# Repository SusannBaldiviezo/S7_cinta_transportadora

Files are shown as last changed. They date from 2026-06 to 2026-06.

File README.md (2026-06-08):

Markdown# Sistema Automático de Clasificación de Frutas

**Universidad:** Universidad Católica Boliviana "San Pablo"
**Materia:** Sistemas Embebidos II
**Docente:** Msc. Ing. Alan Cornejo Q.

**Universidad:** Universidad Católica Boliviana "San Pablo"  
**Materia:** Sistemas Embebidos II  
**Docente:** Msc. Ing. Alan Cornejo Q.  

**Semestre:** 1/2026
=======
**Semestre:** 1/2026  

**Estudiantes:** - Susann Baldiviezo C.  
- Alejandro Bejarano R.  
- Florencia Frigerio A.  
- Benjamín Soruco G.  

---

## Descripción

El objetivo principal de este proyecto es automatizar, mediante una cinta transportadora, la selección y clasificación de tomates en las zonas productoras del departamento de Tarija. Para dar solución a esta necesidad, se presenta este prototipo a escala como una alternativa tecnológica eficiente.

El sistema realiza la clasificación automática mediante visión artificial y un microcontrolador ESP32. Detecta tomates en estado de descomposición a través de dos cámaras USB y OpenCV, activa un mecanismo de desviación controlado por **dos servomotores** para expulsarlos de la banda transportadora, y permite al operario monitorear y controlar todo el proceso desde una consola portátil inalámbrica.

## Arquitectura general

[2 Cámaras USB]│▼[PC — Python + OpenCV]  ──────────────────────────────────────────┐│  publica fruta/estado                                     │▼                                                           │[Raspberry Pi — Mosquitto MQTT]  (AP: CintaTransportadora)        ││  distribuye                                               │├────────────────────────┐                                  │▼                        ▼                                  │[ESP32 Motor]          [ESP32 Consola]  ◄── operario              │BTS7960                Pantalla OLED                           │Banda DC               4 botones                               │2 Servomotores                                                 ││                        │                                  │▼                        ▼                                  │[Motor 12V]          [Pantalla de estado]  ───────────────────────┘[Mecanismo Desviador]
## Estructura del repositorio

├── README.md              ← este archivo├── ARCHITECTURE.md        ← diagrama detallado del sistema├── SETUP.md               ← cómo levantar el proyecto de cero├── .gitignore│├── docs/                  ← documentación completa├── esp32/                 ← firmware embebido (motor + consola)├── hardware/              ← conexiones, pinouts, datasheets├── ml/                    ← módulo de visión artificial (OpenCV/YOLO)├── rpi/                   ← scripts Python para la Raspberry Pi├── scripts/               ← herramientas y simuladores├── config/                ← configuración de servicios (Mosquitto, etc.)├── requirements/          ← dependencias por módulo├── tests/                 ← pruebas de integración└── dashboard/             ← interfaz web 
## Inicio rápido

```bash
# 1. Clonar el repositorio
git clone <url-del-repo>
cd S7_cinta_transportadora

# 2. Ver guía de instalación
cat SETUP.md

# 3. Instalar dependencias Python
pip install -r requirements/rpi_requirements.txt

# 4. Compilar y flashear ESP32 motor (desde esp32/motor_controller/)
idf.py build
idf.py -p COM3 flash monitor

# 5. Compilar y flashear ESP32 consola (desde esp32/console_esp32/)
idf.py build
idf.py -p COM4 flash monitor

# 6. Ejecutar el sistema principal
python ml/main_vision.py
Estado del proyectoComponenteEstadoRPi + Mosquitto MQTT✅ CompletadoESP32 Motor (BTS7960 + 2 Servomotores)✅ CompletadoRPi como Access Point✅ CompletadoESP32 Consola (Pantalla OLED + botones)✅ CompletadoMódulo OpenCV (Visión artificial para tomates)✅ CompletadoIntegración y Pruebas en Banda✅ CompletadoDashboard web✅ Completado

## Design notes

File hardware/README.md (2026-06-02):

# Hardware

## Lista de componentes

| ID | Componente | Descripción | Estado |
|---|---|---|---|
| H-01 | ESP32 WROOM-32 | Microcontrolador principal (motor) | ✅ |
| H-02 | 2x Cámaras USB | Captura de imágenes de frutas | ⬜ pendiente |
| H-03 | Cilindro neumático | Expulsión física de fruta rechazada | ✅ |
| H-04 | Válvula solenoide 12V | Controla aire al cilindro (via relé) | ✅ |
| H-05 | Motor DC 12V + banda | Transporte de fruta | ✅ |
| H-06 | Compresor de aire | Suministro neumático | ✅ |
| H-07 | PC/Laptop | Procesamiento OpenCV | ✅ |
| H-08 | Fuente 12V | Alimenta motor y válvula | ✅ |
| H-09 | Iluminación LED | Luz controlada sobre zona de inspección | ⬜ pendiente |
| H-10 | ESP32 WROOM-32 | Microcontrolador consola portátil | ✅ |
| H-11 | LCD 16x2 I2C | Display consola (módulo PCF8574) | ✅ |
| H-12 | Powerbank 5V | Alimentación autónoma consola | ✅ |
| H-13 | 4x pulsadores | Botones de control operario | ✅ |
| H-14 | LED + resistencia 220Ω | Indicador de alerta | ✅ |
| H-15 | BTS7960 (IBT-2) | Driver puente H para motor DC | ✅ |
| H-16 | Relé 5V | Control de válvula solenoide | ✅ |

## Conexiones ESP32 Motor ↔ BTS7960

```
ESP32 GPIO 25  →  BTS7960 RPWM   (PWM giro adelante)
ESP32 GPIO 26  →  BTS7960 LPWM   (PWM giro atrás)
ESP32 GPIO 32  →  BTS7960 R_EN   (habilita lado derecho)
ESP32 GPIO 33  →  BTS7960 L_EN   (habilita lado izquierdo)
ESP32 5V (VIN) →  BTS7960 VCC
ESP32 GND      →  BTS7960 GND    ← tierra común obligatoria

Fuente 12V (+) →  BTS7960 B+
Fuente 12V (-) →  BTS7960 B-     ← misma tierra común
BTS7960 M+     →  Motor (+)
BTS7960 M-     →  Motor (-)
```

## Conexiones ESP32 Motor ↔ Relé ↔ Válvula

```
ESP32 GPIO 27   →  Relé IN
ESP32 5V (VIN)  →  Relé VCC
ESP32 GND       →  Relé GND      ← tierra común
Fuente 12V (+)  →  Relé COM
Relé NO         →  Válvula (+)
Válvula (-)     →  Fuente 12V (-) ← tierra común
```

## Conexiones ESP32 Consola ↔ LCD I2C

```
ESP32 GPIO 21  →  LCD SDA
ESP32 GPIO 22  →  LCD SCL
ESP32 5V (VIN) →  LCD VCC
ESP32 GND      →  LCD GND

Dirección I2C por defecto: 0x27
(Si no funciona, probar: 0x3F)
```

## Conexiones Botones y LED (consola)

```
GPIO 14 → Botón INICIAR → GND   (pull-up interno activo)
GPIO 27 → Botón DETENER → GND
GPIO 26 → Botón PANTALLA → GND
GPIO 25 → Botón RESET → GND
GPIO 2  → Resistencia 220Ω → LED ánodo → LED cátodo → GND
```

## Tierra común — crítica

Todos los GND deben estar unidos:
- ESP32 GND
- BTS7960 GND (señales)
- BTS7960 B- (potencia)
- Fuente 12V (-)
- Relé GND

Sin tierra común, el sistema se comporta de forma errática.

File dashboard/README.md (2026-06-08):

# Sistema Clasificador de Frutas — Dashboard

Panel de control web en tiempo real para el sistema de clasificación de tomates con cinta transportadora.  
Desarrollado para UCB San Pablo · Sistemas Embebidos II · 2026.

---

## Arquitectura general

```
[ESP32 Cinta]  ──────────┐
                         ├─── WiFi ───► [Raspberry Pi AP]
[ESP32 Consola] ─────────┘               192.168.4.1
    (botones + OLED)                      │
                                          ├─ Mosquitto MQTT :1883
                                          ├─ FastAPI backend :8080
                                          └─ React frontend (servido por FastAPI)
```

La Raspberry Pi actúa como **punto de acceso WiFi** con SSID `CintaTransportadora`. Cualquier dispositivo conectado a esa red puede abrir el dashboard en `http://192.168.4.1:8080`.

---

## Estructura del proyecto

```
dashboard/
├── main.py            # Backend FastAPI + bridge MQTT (paho-mqtt)
├── data/
│   └── frutas.csv     # Historial persistente de clasificaciones
├── static/            # Build de React (generado con npm run build)
│   ├── index.html
│   └── assets/
└── frontend/          # Código fuente React + Vite
    ├── src/
    │   ├── App.jsx
    │   ├── index.css          # Sistema de diseño (variables CSS, tipografías)
    │   ├── api.js             # Llamadas HTTP al backend
    │   ├── hooks/
    │   │   └── useDashboard.js  # Polling cada 1500ms
    │   └── components/
    │       ├── Header.jsx
    │       ├── StatusCards.jsx
    │       ├── ControlPanel.jsx
    │       ├── AdminPanel.jsx
    │       ├── ConveyorPanel.jsx   # Animación cinta + bins de clasificación
    │       ├── CameraPanel.jsx     # Vista cámara + resultado de clasificación
    │       ├── OledMirror.jsx      # Espejo de la OLED del ESP32 Consola
    │       ├── CountersPanel.jsx
    │       ├── ChartsRow.jsx
    │       └── HistoryTable.jsx
    └── package.json
```

---

## MQTT — Tópicos

| Tópico | Dirección | Contenido |
|---|---|---|
| `fruta/estado` | ESP32 Cinta → todos | `aceptada` / `podrida` / `verde` |
| `sistema/motor` | ESP32 Cinta → todos | `activo` / `detenido` |
| `operario/comando`  | Dashboard/Consola → Cinta | `iniciar` / `detener` |
| `operario/pantalla` | Dashboard → Consola | Número de pantalla `0`, `1`, `2` |
| `operario/reset` | Dashboard → Consola | `reset` |
| `consola/pantalla`  | ESP32 Consola → Dashboard | Número de pantalla al presionar BTN |
| `consola/reset` | ESP32 Consola → Dashboard | `reset` al presionar BTN_RESET |

### Sincronización bidireccional

- **Botones ESP32 → Dashboard**: el ESP32 publica en `operario/comando`, `consola/pantalla` y `consola/reset`. El backend escucha y actualiza el estado. El frontend hace polling cada 1,5 s.
- **Dashboard → ESP32**: el backend publica en `operario/comando`, `operario/pantalla` y `operario/reset`. El ESP32 Consola está suscrito a todos estos.

---

## OLED Consola (SSD1306 128×64)

Tres pantallas, se ciclan con BTN_PANTALLA (GPIO 16) o desde el botón "Cambiar Pantalla" del dashboard:

| Pantalla | Contenido |
|---|---|
| 0 — CONTADORES FRUTA | Aceptadas / Podridas / Verdes + estado motor |
| 1 — DIAGNOSTICO SIST | Total clasificadas + rechazos consecutivos |
| 2 — SISTEMA ALERTAS  | Alerta parpadeante si rechazos consecutivos ≥ 3 |

El panel **Consola OLED** en el dashboard es un espejo fiel de lo que muestra el ESP32. Desde ahí también se puede:

- **Cambiar Pantalla** → publica `operario/pantalla` vía MQTT (el ESP32 cambia su OLED físico)
- **Reiniciar Contadores** → publica `operario/reset` vía MQTT (ambos dispositivos resetean sus contadores)

---

## Pines ESP32 Consola

| Pin | Función |
|---|---|
| GPIO 18  | BTN_INICIAR — arranca la cinta |
| GPIO 17  | BTN_DETENER — para la cinta |
| GPIO 16  | BTN_PANTALLA — cicla la pantalla OLED |
| GPIO 4 | BTN_RESET — reinicia contadores de sesión |
| GPIO 2 | LED estado (parpadeo rápido = sin WiFi; lento = alerta) |
| GPIO 21  | SDA OLED I2C |
| GPIO 22  | SCL OLED I2C |

---

## Instalación y despliegue

### En la Raspberry Pi

```bash
# Instalar dependencias Python (una sola vez)
pip install fastapi uvicorn paho-mqtt

# Ejecutar el backend (desde la carpeta dashboard/)
python main.py
```

El servidor queda escuchando en `0.0.0.0:8080` y se reconecta automáticamente a MQTT si pierde la conexión.

### Compilar el frontend (desde Windows)

```bash
cd frontend
npm install        # solo la primera vez
npm run build      # genera ../static/
```

### Subir cambios a la Raspberry Pi

```bash
# Copiar el build y el backend actualizado
scp -r static/ main.py pi@192.168.4.1:~/dashboard/

# Reiniciar el backend en la Pi
ssh pi@192.168.4.1 "pkill -f main.py; cd ~/dashboard && python main.py &"
```

### Acceder al dashboard

Conectarse a la red WiFi `CintaTransportadora` y abrir:

```
http://192.168.4.1:8080
```

Múltiples dispositivos pueden conectarse simultáneamente; todos ven el mismo estado en tiempo real.

---

## Conexión de red

| Parámetro | Valor |
|---|---|
| SSID | `CintaTransportadora` |
| Contraseña WiFi  | `cinta2026` |
| IP Raspberry Pi  | `192.168.4.1` |
| Dashboard | `http://192.168.4.1:8080`  |
| MQTT broker | `192.168.4.1:1883` |

El rango DHCP asigna IPs en `192.168.4.2 – 192.168.4.20`. Pueden conectarse múltiples clientes simultáneamente.

---

## API del backend

| Método | Ruta | Descripción |
|---|---|---|
| GET | `/api/estado` | Estado actual del sistema |
| GET | `/api/stats` | Estadísticas globales + por hora |
| GET | `/api/frutas?limit=N` | Últimas N clasificaciones |
| POST | `/api/control/start` | Arrancar motor |
| POST | `/api/control/stop` | Detener motor |
| POST | `/api/control/reset` | Reiniciar contadores de sesión |
| POST | `/api/control/pantalla` | Ciclar pantalla OLED al siguiente índice |
| POST | `/api/admin/fruta/{tipo}` | Simular clasificación (modo admin) |
| POST | `/api/admin/motor/{cmd}` | Simular comando motor (modo admin) |

---

## Diseño visual

| Variable | Valor |
|---|---|
| Fondo base | `#131c25` |
| Panel | Gradiente `#1f2d39 → #192530 → #152130` |
| Acento | `#2d80b8` (azul SCADA) |
| OK / Mala / Verde  | `#3a9650` / `#b03830` / `#b88820` |
| Tipografía display | Barlow Semi Condensed |
| Tipografía body | Barlow |
| Tipografía mono | JetBrains Mono |
| Border radius | 7px |

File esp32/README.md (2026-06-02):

# Firmware ESP32

## Proyectos

| Carpeta | Descripción | Puerto |
|---|---|---|
| `motor_controller/` | Control de banda (BTS7960) + válvula solenoide + MQTT | COM3 |
| `console_esp32/` | Consola portátil: LCD 16x2 + 4 botones + LED + MQTT | COM4 |

## Compilar y flashear

```bash
# ESP32 Motor
cd motor_controller
idf.py set-target esp32
idf.py build
idf.py -p COM3 flash monitor

# ESP32 Consola
cd ../console_esp32
idf.py set-target esp32
idf.py build
idf.py -p COM4 flash monitor
```

> En Linux usar `/dev/ttyUSB0` y `/dev/ttyUSB1` en lugar de COM3/COM4.  
> Para salir del monitor: `Ctrl + ]`

## Credenciales de red (ambos proyectos)

```c
#define WIFI_SSID      "CintaTransportadora"
#define WIFI_PASSWORD  "cinta2026"
#define MQTT_BROKER    "mqtt://192.168.4.1:1883"
```

Estas están definidas en:
- `motor_controller/main/config.h`
- `console_esp32/main/esp32_consola.c` (líneas 20-22)

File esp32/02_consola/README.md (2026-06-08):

# Proyecto: 02_consola (Clasificador de Frutas)

Este es el proyecto de la consola para el sistema clasificador de frutas utilizando ESP-IDF, MQTT y una pantalla LCD I2C.

## Comandos Útiles de ESP-IDF

Aquí tienes una lista de los comandos esenciales que necesitarás ejecutar en la terminal (PowerShell) para trabajar con este proyecto:

### 1. Activar el entorno de ESP-IDF
Este comando es **obligatorio** cada vez que abres una nueva ventana de PowerShell antes de poder usar `idf.py`:
```powershell
C:\esp\v6.0\esp-idf\export.ps1
```

### 2. Configurar el proyecto
Abre el menú de configuración visual para ajustar parámetros del hardware, WiFi, MQTT, etc.:
```powershell
idf.py menuconfig
```

### 3. Compilar el proyecto
Construye el código fuente (crea los ejecutables binarios). La primera vez puede tardar un poco:
```powershell
idf.py build
```

### 4. Subir el código al ESP32 (Flashear)
*Nota: Cambia `COMx` por el puerto COM donde esté conectado tu ESP32 (ej. `COM3` o en Linux `/dev/ttyUSB0`)*
```powershell
idf.py -p COMx flash
```

### 5. Ver el monitor serie
Abre el monitor para ver los mensajes (`ESP_LOGI`, `printf`, etc.) que el ESP32 imprime en tiempo real:
```powershell
idf.py -p COMx monitor
```
*(Para salir del monitor serie presiona `Ctrl` + `]`)*

### 6. Compilar, flashear y monitorear (Todo en uno)
El comando más usado durante el desarrollo. Hace todo el proceso de un solo golpe:
```powershell
idf.py -p COMx flash monitor
```

### 7. Limpiar la compilación (Clean)
Útil si el código hace cosas raras y quieres forzar una compilación desde cero borrando todos los archivos temporales generados:
```powershell
idf.py fullclean
```
## Pasos realizados para que el proyecto compile

1. **Activar el entorno ESP‑IDF**  
   Ejecuta el script de exportación de PowerShell (solo una vez por sesión):

   ```powershell
   C:\esp\v6.0\esp-idf\export.ps1
   ```

2. **Compilar el proyecto**  

   ```powershell
   idf.py build
   ```

   La compilación se completa sin el error `-Werror=format-truncation` porque los buffers del LCD fueron ampliados a 64 bytes en `esp32_consola.c`.

3. **Flashear y monitorizar** (sólo cuando el ESP‑32 esté conectado):

   ```powershell
   idf.py -p COMx flash monitor
   ```

Con estos pasos el proyecto se construye y puede ser cargado en el ESP‑32.  
Si abres una nueva ventana de PowerShell, repite el paso 1 antes de ejecutar los demás comandos.

## Pruebas de MQTT (Simulando la Raspberry Pi)

Para comprobar que el sistema recibe correctamente los mensajes del clasificador y actualiza los contadores, puedes enviar mensajes MQTT manualmente simulando ser la Raspberry Pi.

1. **Conéctate a tu Raspberry Pi** desde una nueva ventana de PowerShell:
   ```bash
   ssh raspi@192.168.1.100
   ```

2. **Aceptar frutas:**
   Envía este comando para simular que pasó una fruta "aceptada". Puedes enviarlo varias veces y ver cómo sube el contador "OK" en la LCD:
   ```bash
   mosquitto_pub -h localhost -t "fruta/estado" -m "aceptada"
   ```

3. **Rechazar frutas:**
   Envía este comando para simular una fruta "rechazada". El contador "Rej" debería subir:
   ```bash
   mosquitto_pub -h localhost -t "fruta/estado" -m "rechazada"
   ```

4. **Probar la Alerta:**
   Si mandas 3 rechazos consecutivos, el sistema debería entrar en modo `!!! ALERTA !!!` y hacer parpadear el LED de la consola:
   ```bash
   mosquitto_pub -h localhost -t "fruta/estado" -m "rechazada"
   mosquitto_pub -h localhost -t "fruta/estado" -m "rechazada"
   mosquitto_pub -h localhost -t "fruta/estado" -m "rechazada"
   ```
   *(Para salir del estado de alerta, simplemente presiona el Botón 4 "RESET" en tu placa).*

5. **Probar el Relé / Motor / Válvula:**
   La consola **no** tiene el relé conectado. Para probar que el relé se activa, asegúrate de que la otra ESP32 (proyecto `01_motor`) esté encendida, conectada al WiFi y escuchando a MQTT. Luego envía el comando directo para la válvula:
   ```bash
   mosquitto_pub -h localhost -t "sistema/valvula" -m "abrir"
   ```

## FASE 8: Pruebas de Portabilidad (Powerbank)

1. Desconecta el cable USB de la PC.
2. Conecta la ESP32 (Consola) a un **Powerbank**.
3. El sistema debería encender y reconectarse al WiFi / MQTT automáticamente.
4. Llévala caminando por la habitación para comprobar que el WiFi se mantiene en rango sin perder la conexión.

✅ **¡Listo! Consola portátil operativa y funcionando al 100%.**

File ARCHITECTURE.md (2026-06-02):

# Arquitectura del Sistema

## Diagrama de capas

```
┌─────────────────────────────────────────────────────────┐
│                   CAPA DE ENTRADA                        │
│   [Cámara USB 1]    [Cámara USB 2]   [Sensor presencia] │
│        ↓ ángulo frontal  ↓ ángulo lateral   ↓ opcional  │
└──────────────────────┬──────────────────────────────────┘
                       │ frames de video
┌──────────────────────▼──────────────────────────────────┐
│                 CAPA DE PROCESAMIENTO                    │
│              PC / Laptop — Python 3.x                   │
│   ┌─────────────────────────────────────────────────┐   │
│   │  capture.py  →  OpenCV analysis  →  decision   │   │
│   │  (color + textura → "aceptada" | "rechazada")  │   │
│   └─────────────────┬───────────────────────────────┘   │
│                     │ publica a MQTT                     │
└─────────────────────┼───────────────────────────────────┘
                      │
┌─────────────────────▼───────────────────────────────────┐
│               CAPA DE MENSAJERÍA (MQTT)                 │
│         Raspberry Pi — Mosquitto Broker v2.x            │
│         Red WiFi: CintaTransportadora (AP)              │
│         IP: 192.168.4.1  Puerto: 1883                   │
│                                                         │
│  Tópicos:                                               │
│    fruta/estado      → "aceptada" | "rechazada"         │
│    operario/comando  → "iniciar" | "detener"            │
│    sistema/motor     → "activo" | "detenido" | "online" │
│    sistema/valvula   → "disparada"                      │
└───────────────┬───────────────────────┬─────────────────┘
                │                       │
┌───────────────▼───────────┐ ┌─────────▼───────────────┐
│    ESP32 MOTOR            │ │   ESP32 CONSOLA          │
│    (motor_controller)     │ │   (console_esp32)        │
│                           │ │                          │
│  BTS7960 (GPIO 25,26,32,33│ │  LCD 16x2 I2C            │
│  Válvula (GPIO 27 → relé) │ │  4 botones (GPIO 14,25,  │
│  Motor DC 12V             │ │            26,27)        │
│  Cilindro neumático       │ │  LED indicador (GPIO 2)  │
│                           │ │  Alimentado por powerbank│
└───────────────────────────┘ └──────────────────────────┘
```

## Flujo de datos

```
1. Fruta entra a la banda transportadora
2. Cámaras capturan imagen desde 2 ángulos
3. PC analiza color y textura con OpenCV
4. PC publica veredicto en MQTT (fruta/estado)
5. Mosquitto distribuye el mensaje a todos los suscriptores
6. ESP32 Motor recibe "rechazada" → dispara válvula → cilindro expulsa fruta
7. ESP32 Consola recibe el mismo mensaje → actualiza LCD y contadores
8. Operario puede iniciar/detener desde consola → ESP32 Consola publica en operario/comando
9. ESP32 Motor escucha operario/comando → arranca o para el motor
```

## Topología de red

```
[Raspberry Pi]
    wlan0: 192.168.4.1  ← Access Point "CintaTransportadora"
    eth0:  192.168.1.100 ← Ethernet (opcional, para configuración)
    
Clientes WiFi:
    ESP32 Motor:   192.168.4.X (DHCP)
    ESP32 Consola: 192.168.4.Y (DHCP)
    PC/Laptop:     192.168.4.Z (DHCP)
```

## Tópicos MQTT

| Tópico | Publicado por | Suscrito por | Valores |
|---|---|---|---|
| `fruta/estado` | PC (OpenCV) | ESP32 Motor, ESP32 Consola | `aceptada`, `rechazada` |
| `operario/comando` | ESP32 Consola | ESP32 Motor | `iniciar`, `detener` |
| `sistema/motor` | ESP32 Motor | ESP32 Consola | `activo`, `detenido`, `esp32_online` |
| `sistema/valvula` | ESP32 Motor | ESP32 Consola | `disparada` |

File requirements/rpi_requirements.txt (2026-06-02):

# Dependencias Python para la Raspberry Pi y PC central
# Instalar con: pip install -r rpi_requirements.txt

paho-mqtt>=1.6.0
pyserial>=3.5

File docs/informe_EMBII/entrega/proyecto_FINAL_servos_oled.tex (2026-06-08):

% ====================================================================
%  Sistema Automatico de Clasificacion de Tomates -- Sistemas Embebidos II
%  Plantilla DCT - UCB San Pablo
%  VERSIÓN ACTUALIZADA: Servomotores MG996R + OLED
%  Editar SOLO este archivo (no tocar catolica_proyectos.cls)
% ====================================================================
\documentclass[12pt]{catolica_proyectos}
\addbibresource{bibliografia.bib}

% ---------------- PAQUETES ADICIONALES ----------------
\usepackage[T1]{fontenc}
\usepackage{float}
\usepackage{booktabs}
\usepackage{array}
\usepackage{siunitx}
\usepackage{listings}
\usepackage{tikz}
\usetikzlibrary{positioning,arrows.meta,shapes.geometric,automata,calc,fit,backgrounds}

% ---------------- COLORES ----------------
\definecolor{azulucb}{HTML}{1F4E79}
\definecolor{naranja}{HTML}{C55A11}
\definecolor{verdeok}{HTML}{2E7D32}
\definecolor{rojoerr}{HTML}{C0392B}
\definecolor{grisbox}{HTML}{F2F2F2}
\definecolor{griscmt}{HTML}{6A737D}

% ---------------- ESTILOS DE CODIGO ----------------
\lstset{
  basicstyle=\ttfamily\scriptsize,
  keywordstyle=\color{azulucb}\bfseries,
  commentstyle=\color{griscmt}\itshape,
  stringstyle=\color{verdeok},
  numbers=left, numberstyle=\tiny\color{griscmt}, numbersep=7pt,
  backgroundcolor=\color{grisbox},
  frame=single, rulecolor=\color{griscmt!50},
  breaklines=true, showstringspaces=false, tabsize=2,
  captionpos=b, extendedchars=true, inputencoding=utf8,
  literate=%
    {á}{{\'a}}1 {é}{{\'e}}1 {í}{{\'i}}1 {ó}{{\'o}}1 {ú}{{\'u}}1
    {Á}{{\'A}}1 {É}{{\'E}}1 {Í}{{\'I}}1 {Ó}{{\'O}}1 {Ú}{{\'U}}1
    {ñ}{{\~n}}1 {Ñ}{{\~N}}1 {ü}{{\"u}}1 {¿}{{?`}}1 {¡}{{!`}}1 {°}{{\textdegree}}1
}
\lstdefinestyle{C}{language=C}
\lstdefinestyle{py}{language=Python}
\lstdefinestyle{sh}{language=bash, numbers=none}

% ---------------- ESTILOS TikZ ----------------
\tikzset{
  bloque/.style={rectangle, rounded corners=2pt, draw=azulucb, very thick,
    fill=azulucb!8, align=center, minimum height=1cm, inner sep=5pt},
  cap/.style={rectangle, draw=griscmt, dashed, inner sep=8pt, rounded corners},
  flecha/.style={-{Stealth[length=2.5mm]}, thick},
  flechabi/.style={{Stealth[length=2.5mm]}-{Stealth[length=2.5mm]}, thick},
}

% ---------------- PLACEHOLDER PARA FOTOS REALES ----------------
\newcommand{\fotopendiente}[2][7cm]{%
  \fcolorbox{griscmt}{grisbox}{%
    \parbox[c][#1][c]{0.82\textwidth}{\centering\itshape\color{griscmt}
      [\,FOTOGRAFÍA REAL A INCORPORAR\,]\\[2pt] #2}}}

% ---------------- DATOS DEL PROYECTO ----------------
\titulo{Sistema Automático de Clasificación de Tomates mediante Visión Artificial y ESP32}
\materia{Sistemas Embebidos II}
\carrera{Mecatrónica}
\autor{Susann Baldiviezo C. \\ Alejandro Bejarano R. \\ Florencia Frigerio A. \\ Benjamín Soruco G.}
\docente{Msc. Ing. Alan Cornejo Q.}
\semestre{1/2026}

\begin{document}

\maketitle
\pagestyle{empty}
\tableofcontents
\newpage
\listoffigures
\newpage
\listoftables
\newpage

\pagenumbering{arabic}
\setcounter{page}{1}

% ====================================================================
\section{Descripción técnica-conceptual del proyecto a realizar}
% ====================================================================

El proyecto consiste en el diseño e implementación de un sistema automático de clasificación de tomates sobre una banda transportadora, que separa físicamente los frutos en buen estado de aquellos en estado de descomposición. La detección se realiza por visión artificial con OpenCV \cite{opencv2024,gonzalez2018dip}, mientras que toda la cadena de control, actuación, comunicación y monitoreo se resuelve con \textbf{sistemas embebidos basados en el microcontrolador ESP32} \cite{espressif2023trm}, que constituyen el núcleo de este documento.

El sistema se organiza en cuatro capas: (i)~\emph{adquisición}, con cámaras USB sobre la banda; (ii)~\emph{procesamiento}, en una PC que ejecuta el algoritmo de visión; (iii)~\emph{mensajería}, en una Raspberry Pi que actúa como \emph{broker} MQTT \cite{light2017mosquitto} y punto de acceso WiFi; y (iv)~\emph{actuación y monitoreo}, con dos ESP32 independientes: uno controla el motor de la banda y dos servomotores MG996R para desvío, y el otro es una consola portátil inalámbrica para el operario. La PC emite un veredicto binario por cada fruto (\texttt{aceptada} o \texttt{rechazada}) y lo publica en la red; los nodos embebidos reaccionan a ese mensaje en tiempo real.

El principal desafío técnico no está en la visión, sino en la \textbf{coordinación distribuida en tiempo real} entre nodos heterogéneos sin un cableado punto a punto: tres equipos (PC y dos ESP32) deben compartir estado de forma confiable, con baja latencia y de manera robusta ante desconexiones, sobre una red local que además debe funcionar \emph{sin acceso a Internet}. La propuesta de valor es ofrecer una solución de control de calidad poscosecha automatizada, portátil y de bajo costo, reproducible con componentes disponibles en el mercado local, orientada a pequeños productores (Sección~\ref{sec:tarija}).

En la Figura~\ref{fig:bloques} se presenta el diagrama en bloques del sistema. Se observa la separación en capas y, en particular, que la Raspberry Pi concentra la mensajería: ningún nodo se comunica directamente con otro, sino que todos publican y se suscriben a través del \emph{broker}, lo que desacopla a los dispositivos entre sí.

\begin{figure}[H]
  \centering
  \begin{tikzpicture}[node distance=8mm and 14mm]
    % Capa entrada
    \node[bloque] (cam) {3 Cámaras USB\\(estrategia multivista)};
    % Capa procesamiento
    \node[bloque, below=of cam] (pc) {PC / Laptop\\Python + OpenCV\\\footnotesize veredicto: aceptada / rechazada};
    % Broker
    \node[bloque, fill=naranja!12, draw=naranja, below=of pc] (rpi)
      {Raspberry Pi\\\textbf{Broker MQTT (Mosquitto)} + Access Point WiFi\\\footnotesize SSID \texttt{CintaTransportadora} -- 192.168.4.1:1883};
    % Nodos embebidos
    \node[bloque, fill=verdeok!10, draw=verdeok, below left=14mm and -10mm of rpi] (m)
      {\textbf{ESP32 Motor}\\Driver BTS7960 (PWM)\\2 Servomotores MG996R};
    \node[bloque, fill=verdeok!10, draw=verdeok, below right=14mm and -10mm of rpi] (c)
      {\textbf{ESP32 Consola}\\Pantalla OLED I\textsuperscript{2}C\\4 botones + Powerbank};
    % Actuadores
    \node[bloque, below=of m] (act) {Motor DC 12\,V + banda\\Servomotores para desvío};
    \node[bloque, below=of c] (op) {Operario\\(monitoreo y control)};

    \draw[flecha] (cam) -- node[right,font=\footnotesize]{frames} (pc);
    \draw[flecha] (pc) -- node[right,font=\footnotesize]{publish \texttt{fruta/estado}} (rpi);
    \draw[flechabi] (rpi) -- node[above left,font=\footnotesize]{MQTT/WiFi} (m);
    \draw[flechabi] (rpi) -- node[above right,font=\footnotesize]{MQTT/WiFi} (c);
    \draw[flecha] (m) -- (act);
    \draw[flechabi] (c) -- (op);
  \end{tikzpicture}
  \caption{Diagrama en bloques del sistema actualizado con servomotores MG996R. La Raspberry Pi actúa como concentrador de mensajería (broker MQTT) y punto de acceso WiFi; los nodos se comunican de forma indirecta a través de tópicos.}
  \label{fig:bloques}
\end{figure}

% ====================================================================
\section{Propósito del proyecto}
% ====================================================================

El propósito es automatizar la clasificación poscosecha de tomate por estado de sanidad (sano vs. deteriorado), integrando visión artificial con un sistema embebido distribuido que controle los actuadores y permita la supervisión del operario en tiempo real. En concreto se busca:

\begin{itemize}
  \item Reducir la intervención humana en una tarea repetitiva y con alto margen de error visual, separando automáticamente el fruto deteriorado.
  \item Disminuir las pérdidas económicas asociadas a la comercialización de fruto en mal estado y al contagio de la podredumbre dentro del lote.
  \item Demostrar la viabilidad técnica de coordinar varios nodos embebidos ESP32 con una PC mediante un protocolo de mensajería liviano (MQTT) sobre una red WiFi local autónoma.
  \item Aplicar de forma integrada los contenidos de \emph{Sistemas Embebidos II}: GPIO, PWM, I\textsuperscript{2}C, conectividad WiFi, multitarea con FreeRTOS \cite{barry2016freertos} y control de actuadores de potencia.
\end{itemize}

Desde lo académico, el énfasis está en el \textbf{firmware embebido y la arquitectura de comunicaciones}; la visión artificial se trata como un módulo proveedor de veredictos cuya implementación interna es intercambiable.

% ====================================================================
\section{Alcance del proyecto}
% ====================================================================

El proyecto abarca el diseño, la construcción y la validación de un prototipo funcional. A continuación se delimita el alcance.

\subsection{Lo que el sistema SÍ contempla}
\begin{itemize}
  \item Firmware embebido para dos ESP32 desarrollado sobre ESP-IDF v5.x \cite{espressif2024idf}: control de motor por PWM, disparo de servomotores, lectura de botones y manejo de display OLED.
  \item Control de la banda transportadora mediante driver de potencia BTS7960 (puente H) \cite{infineon2013bts7960}.
  \item Expulsión física del fruto rechazado mediante dos servomotores MG996R acoplados mecánicamente con precisión angular de $\pm 5°$.
  \item Arquitectura de comunicaciones completa: red WiFi local con la Raspberry Pi como Access Point y \emph{broker} MQTT, definición de tópicos, calidad de servicio y secuencia de mensajes.
  \item Consola portátil (segunda ESP32) con pantalla OLED I\textsuperscript{2}C (128x64 px), cuatro botones, alimentada por \emph{powerbank} 12000\,mAh, para monitoreo y control inalámbrico.
  \item Clasificación binaria: \emph{buen estado} / \emph{mal estado}, bajo iluminación controlada de laboratorio.
\end{itemize}

\subsection{Lo que el sistema NO contempla}
El presente proyecto no incluye:
\begin{itemize}
  \item Clasificación por tamaño, peso o grado de madurez (solo estado de descomposición).
  \item Operación en líneas industriales de alta velocidad o con varios tipos de fruta en simultáneo.
  \item Seguridad/cifrado de la red MQTT (se asume red local privada y aislada).
  \item Integración con sistemas ERP o trazabilidad industrial.
\end{itemize}

% ====================================================================
\section{Supuestos del proyecto}
% ====================================================================

Para el desarrollo del proyecto se supone que:
\begin{itemize}
  \item \textbf{Iluminación controlada:} el prototipo opera bajo luz artificial constante que minimiza variaciones que afecten el análisis de color y textura.
  \item \textbf{Frutos individualizados:} los tomates se colocan sobre la banda separados entre sí, de modo que el sistema los analice de forma independiente.
  \item \textbf{Velocidad de banda calibrada:} la velocidad es fija (14 segundos entre estaciones) y permite a la visión capturar y procesar cada fruto a tiempo (Sección~\ref{sec:respuestas}).
  \item \textbf{Red WiFi local disponible:} la Raspberry Pi genera el Access Point \texttt{CintaTransportadora}; no se requiere Internet.
  \item \textbf{Tierra común:} todos los \texttt{GND} (ESP32, BTS7960, fuente 12\,V, servomotores) están unidos; sin ello el sistema se comporta de forma errática.
  \item \textbf{Ambiente de laboratorio:} el prototipo se diseña para taller académico, no para entornos con polvo, humedad o vibración industrial.
\end{itemize}

% ====================================================================
\section{Requerimientos}
% ====================================================================

\subsection{Requerimientos funcionales}
\begin{enumerate}
  \item \textbf{Sistema principal de clasificación:}
  \begin{enumerate}
    \item RF-01: el sistema debe capturar imágenes de cada fruto y emitir un veredicto binario.
    \item RF-02: la ESP32 Motor debe arrancar/detener la banda según el comando del operario.
    \item RF-03: ante un veredicto \texttt{rechazada}, la ESP32 Motor debe disparar los servomotores y expulsar el fruto.
    \item RF-04: el disparo de los servomotores no debe bloquear la atención de nuevos mensajes MQTT.
  \end{enumerate}
  \item \textbf{Consola portátil del operario:}
  \begin{enumerate}
    \item RF-05: la consola debe mostrar contadores de aceptadas/rechazadas y el estado del motor con latencia menor a 1\,s.
    \item RF-06: el operario debe poder iniciar y detener todo el proceso desde la consola, sin acceder a la PC.
    \item RF-07: la consola debe indicar mediante pantalla OLED un volumen elevado de rechazos consecutivos.
    \item RF-08: la consola debe indicar la pérdida de conexión con el sistema central.
    \item RF-09: la consola debe funcionar de forma autónoma (\emph{powerbank}), sin cables.
  \end{enumerate}
\end{enumerate}

\subsection{Requerimientos no funcionales}
\begin{enumerate}
  \item RNF-01: el tiempo de procesamiento y reacción por fruto no debe superar los 2\,s.
  \item RNF-02: el sistema debe operar de forma continua al menos 30\,min sin fallos.
  \item RNF-03: el firmware debe estar estructurado de forma modular y documentado.
  \item RNF-04: el prototipo debe ser reproducible con componentes de bajo costo del mercado local.
  \item RNF-05: el sistema debe operar sin acceso a Internet (red local autónoma).
\end{enumerate}

\subsection{Requerimientos de hardware}
En la Tabla~\ref{tab:hw} se listan los componentes de hardware. En la Tabla~\ref{tab:sw} se listan las herramientas y bibliotecas de software con sus versiones.

\begin{table}[H]
\centering
\caption{Componentes de hardware del sistema (actualizado con servomotores).}
\label{tab:hw}
\footnotesize
\begin{tabular}{@{}llc@{}}
\toprule
\textbf{ID} & \textbf{Componente} & \textbf{Cant.} \\
\midrule
H-01 & ESP32 WROOM-32 (nodo Motor) & 1 \\
H-02 & ESP32 WROOM-32 (nodo Consola) & 1 \\
H-03 & Raspberry Pi (broker MQTT + Access Point) & 1 \\
H-04 & Driver BTS7960 / IBT-2 (puente H) & 1 \\
H-05 & Motor DC 12\,V + banda transportadora & 1 \\
H-06 & Servomotor MG996R & 2 \\
H-07 & Fuente 12\,V (motor + servos) & 1 \\
H-08 & 3 cámaras USB & 3 \\
H-09 & PC / Laptop (procesamiento OpenCV) & 1 \\
H-10 & Pantalla OLED I\textsuperscript{2}C 128x64\,px (SSD1306) & 1 \\
H-11 & 4 pulsadores (botones) & 4 \\
H-12 & Powerbank 5\,V 12000\,mAh (alimentación consola) & 1 \\
H-13 & Iluminación LED controlada & 1 \\
\bottomrule
\end{tabular}
\end{table}

\begin{table}[H]
\centering
\caption{Software, frameworks y bibliotecas.}
\label{tab:sw}
\footnotesize
\begin{tabular}{@{}lll@{}}
\toprule
\textbf{Componente} & \textbf{Rol} & \textbf{Versión} \\
\midrule
ESP-IDF & Framework de desarrollo ESP32 & v5.0+ \\
FreeRTOS & RTOS (multitarea) incluido en ESP-IDF & --- \\
\texttt{espressif/mqtt} & Cliente MQTT del ESP32 & IDF v5.x \\
Mosquitto & Broker MQTT (Raspberry Pi) & 2.x \\
NetworkManager (\texttt{nmcli}) & Access Point WiFi en la RPi & --- \\
Python & Módulo de visión y simulador & 3.10+ \\
OpenCV & Visión por computadora & 4.8+ \\
paho-mqtt & Cliente MQTT en Python & 1.6+ \\
\bottomrule
\end{tabular}
\end{table}

% ====================================================================
\section{Entregables principales del proyecto}
% ====================================================================

\begin{table}[H]
\centering
\caption{Entregables del proyecto.}
\label{tab:entregables}
\footnotesize
\begin{tabular}{@{}p{4.2cm}p{8cm}@{}}
\toprule
\textbf{Entregable} & \textbf{Descripción} \\
\midrule
Prototipo físico & Banda con 3 cámaras, servomotores y nodos ESP32 integrados y funcionando. \\
Firmware ESP32 Motor & Código embebido modular (motor, servomotores, MQTT, WiFi) sobre ESP-IDF. \\
Firmware ESP32 Consola & Código de la consola portátil (OLED, botones, MQTT). \\
Configuración Raspberry Pi & Broker Mosquitto, Access Point y servicio \texttt{systemd}. \\
Esquemas y pinouts & Conexiones de hardware y diagramas (Secciones~\ref{sec:firmware}--\ref{sec:respuestas}). \\
Memoria del trabajo final & El presente documento \cite{ucb2026}. \\
Demostración en vivo & Sistema funcionando con tomates reales ante el docente. \\
\bottomrule
\end{tabular}
\end{table}

% ====================================================================
\section{Fundamentos teóricos (conocimientos básicos)}
% ====================================================================

\paragraph{ESP32 y FreeRTOS.} El ESP32 es un SoC con doble núcleo Xtensa LX6, WiFi 802.11 b/g/n y Bluetooth integrados \cite{espressif2023trm}. El framework ESP-IDF lo programa en C sobre \textbf{FreeRTOS}, un kernel de tiempo real que permite ejecutar varias \emph{tareas} concurrentes con planificación por prioridades \cite{barry2016freertos}. Esto es clave en el proyecto: una operación que tarda (girar los servomotores 350\,ms) se delega a una tarea propia para no bloquear la atención de la red.

\paragraph{GPIO y PWM (periférico LEDC).} Los pines de propósito general (GPIO) leen botones. Para regular la velocidad del motor se usa \textbf{PWM} (modulación por ancho de pulso): el periférico \texttt{LEDC} del ESP32 genera una onda cuadrada de frecuencia fija (\SI{10}{\kilo\hertz}) cuyo \emph{ciclo de trabajo} (\emph{duty}, 0--255 en resolución de 8 bits) fija la tensión media aplicada al motor a través del BTS7960. Los servomotores se controlan con PWM a 50\,Hz con ancho de pulso variable (1.0--2.0\,ms para 0°--180°).

\paragraph{Puente H BTS7960.} Es un medio puente de alta corriente; dos integrados forman un puente H completo (módulo IBT-2) capaz de manejar el motor DC de 12\,V, con entradas \texttt{RPWM}/\texttt{LPWM} para sentido/velocidad y \texttt{R\_EN}/\texttt{L\_EN} para habilitación \cite{infineon2013bts7960}.

\paragraph{Servomotor MG996R.} Servomotor de torque alto (11\,kg·cm a 6\,V), velocidad 0.2\,s/60° y rango 0°--180°. Se controla mediante PWM a 50\,Hz; el ancho de pulso (1.0--2.0\,ms) determina la posición angular. Dos servos acoplados mecánicamente permiten expulsar frutos rechazados con precisión y retornar a posición neutral.

\paragraph{I\textsuperscript{2}C y pantalla OLED.} La pantalla OLED 128x64\,px (controlador SSD1306) se comunica por I\textsuperscript{2}C a \SI{100}{\kilo\hertz} (dirección típica \texttt{0x3C}), con solo dos pines (\texttt{SDA} y \texttt{SCL}). Ofrece mejor visibilidad que LCD, bajo consumo de corriente (\SI{20}{\milli\ampere} típico) y funcionamiento con batería.

\paragraph{WiFi (modos STA y AP).} Cada ESP32 opera como estación (STA) y se asocia al Access Point creado por la Raspberry Pi (modo AP). Así se forma una red local cerrada, sin router ni Internet \cite{ieee2020wifi}.

\paragraph{MQTT.} Protocolo de mensajería \emph{publicación/suscripción} liviano sobre TCP, ideal para IoT \cite{banks2014mqtt}. Un \emph{broker} (Mosquitto) recibe mensajes publicados en \emph{tópicos} y los reenvía a los clientes suscritos. La calidad de servicio QoS\,1 garantiza ``al menos una entrega''. Este desacople publicador/suscriptor es lo que permite agregar o quitar nodos sin reconfigurar a los demás.

% ====================================================================
\section{Arquitectura de comunicaciones y protocolos}
\label{sec:comms}
% ====================================================================

Esta es la columna vertebral del sistema. La PC y los dos ESP32 no se comunican entre sí directamente: todos lo hacen a través del \emph{broker} MQTT alojado en la Raspberry Pi.

\subsection{Topología de red}
La Raspberry Pi crea un Access Point WiFi WPA2 (canal 7, banda 2.4\,GHz) mediante \texttt{nmcli}, con IP fija \texttt{192.168.4.1}, y los clientes obtienen IP por DHCP. En la Tabla~\ref{tab:red} se resumen los parámetros de red.

\begin{table}[H]
\centering
\caption{Parámetros de la red local del sistema.}
\label{tab:red}
\footnotesize
\begin{tabular}{@{}ll@{}}
\toprule
\textbf{Parámetro} & \textbf{Valor} \\
\midrule
SSID & \texttt{CintaTransportadora} \\
Seguridad & WPA2-PSK (clave \texttt{cinta2026}) \\
Banda / canal & 2.4\,GHz / 7 \\
IP del broker (RPi, AP) & \texttt{192.168.4.1} \\
Puerto MQTT & \texttt{1883} (TCP) \\
Asignación de IP a clientes & DHCP (\texttt{192.168.4.x}) \\
Autenticación del broker & anónima (\texttt{allow\_anonymous true}) \\
\bottomrule
\end{tabular}
\end{table}

\subsection{Tópicos MQTT}
La Tabla~\ref{tab:topics} define el contrato de comunicación: cada tópico, quién publica, quién se suscribe y los valores válidos. Todos los mensajes se intercambian con QoS\,1.

\begin{table}[H]
\centering
\caption{Tópicos MQTT, publicadores, suscriptores y cargas útiles (payloads).}
\label{tab:topics}
\footnotesize
\begin{tabular}{@{}llll@{}}
\toprule
\textbf{Tópico} & \textbf{Publica} & \textbf{Se suscribe} & \textbf{Valores} \\
\midrule
\texttt{fruta/estado} & PC (OpenCV) & ESP32 Motor, Consola & \texttt{aceptada}, \texttt{rechazada} \\
\texttt{operario/comando} & ESP32 Consola & ESP32 Motor & \texttt{iniciar}, \texttt{detener} \\
\texttt{sistema/motor} & ESP32 Motor & ESP32 Consola & \texttt{activo}, \texttt{detenido}, \texttt{esp32\_online} \\
\texttt{sistema/servos} & ESP32 Motor & ESP32 Consola & \texttt{expulsado} \\
\bottomrule
\end{tabular}
\end{table}

\subsection{Secuencia de mensajes}
La Figura~\ref{fig:seq} muestra la secuencia para dos eventos típicos: el arranque por comando del operario y la llegada de un fruto rechazado. Se aprecia cómo el \emph{broker} replica cada mensaje a todos los suscriptores, de modo que la consola y el motor mantienen estado coherente.

\begin{figure}[H]
  \centering
  \begin{tikzpicture}[font=\footnotesize]
    % Lifelines
    \def\ytop{0} \def\ybot{-7.2}
    \foreach \x/\name in {0/Consola, 4/Broker (RPi), 8/Motor, 12/PC (visión)}{
      \node[bloque, minimum width=2.2cm] at (\x,\ytop) (h\x) {\name};
      \draw[griscmt, dashed] (\x,\ytop-0.6) -- (\x,\ybot);
    }
    % iniciar
    \draw[flecha] (0,-1.0) -- node[above]{pub \texttt{operario/comando=iniciar}} (4,-1.0);
    \draw[flecha] (4,-1.5) -- node[above]{entrega} (8,-1.5);
    \draw[flecha] (8,-2.1) -- node[above]{pub \texttt{sistema/motor=activo}} (4,-2.1);
    \draw[flecha] (4,-2.6) -- node[above]{entrega} (0,-2.6);
    \node[right, griscmt] at (8.2,-2.7) {motor\_avanzar(150)};
    % rechazada
    \draw[flecha] (12,-3.6) -- node[above]{pub \texttt{fruta/estado=rechazada}} (4,-3.6);
    \draw[flecha] (4,-4.1) -- node[above]{entrega} (8,-4.1);
    \draw[flecha] (4,-4.6) -- node[below]{entrega} (0,-4.6);
    \node[right, griscmt] at (8.2,-4.7) {servos\_expulsar()};
    \node[left, griscmt] at (-0.2,-4.7) {rechazadas++};
    \draw[flecha] (8,-5.6) -- node[above]{pub \texttt{sistema/servos=expulsado}} (4,-5.6);
    \draw[flecha] (4,-6.1) -- node[above]{entrega} (0,-6.1);
  \end{tikzpicture}
  \caption{Diagrama de secuencia MQTT para el arranque (comando del operario) y para un fruto rechazado. El broker desacopla a los nodos y replica cada mensaje a los suscriptores.}
  \label{fig:seq}
\end{figure}

% ====================================================================
\section{Diseño del firmware embebido}
\label{sec:firmware}
% ====================================================================

El firmware se desarrolla en C sobre ESP-IDF con un diseño modular. El nodo Motor separa responsabilidades en \texttt{config.h} (pines, red, tópicos), \texttt{motor}, \texttt{servos}, \texttt{mqtt\_handler} y \texttt{wifi\_manager}; el nodo Consola concentra OLED, botones y MQTT con tareas FreeRTOS dedicadas.

\subsection{Pinout del nodo ESP32 Motor}
La Tabla~\ref{tab:pinmotor} detalla la asignación de pines del nodo Motor, derivada de \texttt{config.h} y del cableado del BTS7960 y los servomotores.

\begin{table}[H]
\centering
\caption{Pinout del ESP32 Motor (driver BTS7960 + servomotores MG996R).}
\label{tab:pinmotor}
\footnotesize
\begin{tabular}{@{}lllc@{}}
\toprule
\textbf{GPIO} & \textbf{Señal} & \textbf{Destino} & \textbf{Dir.} \\
\midrule
25 & \texttt{RPWM} (PWM adelante) & BTS7960 RPWM & salida \\
26 & \texttt{LPWM} (PWM atrás) & BTS7960 LPWM & salida \\
32 & \texttt{R\_EN} (habilita der.) & BTS7960 R\_EN & salida \\
33 & \texttt{L\_EN} (habilita izq.) & BTS7960 L\_EN & salida \\
4 & PWM Servo 1 & Servomotor 1 (50\,Hz) & salida \\
5 & PWM Servo 2 & Servomotor 2 (50\,Hz) & salida \\
5V/GND & Alimentación lógica & BTS7960, servos & --- \\
\bottomrule
\end{tabular}
\end{table}

\subsection{Pinout del nodo ESP32 Consola}
La Tabla~\ref{tab:pinconsola} detalla los pines del nodo Consola (OLED I\textsuperscript{2}C, botones con \emph{pull-up} interno).

\begin{table}[H]
\centering
\caption{Pinout del ESP32 Consola (OLED I\textsuperscript{2}C, botones).}
\label{tab:pinconsola}
\footnotesize
\begin{tabular}{@{}lllc@{}}
\toprule
\textbf{GPIO} & \textbf{Señal} & \textbf{Destino} & \textbf{Dir.} \\
\midrule
21 & \texttt{SDA} (I\textsuperscript{2}C) & OLED (SSD1306 @ 0x3C) & E/S \\
22 & \texttt{SCL} (I\textsuperscript{2}C) & OLED (SSD1306 @ 0x3C) & salida \\
14 & Botón INICIAR & a GND (pull-up int.) & entrada \\
27 & Botón DETENER & a GND (pull-up int.) & entrada \\
26 & Botón PANTALLA & a GND (pull-up int.) & entrada \\
25 & Botón RESET & a GND (pull-up int.) & entrada \\
\bottomrule
\end{tabular}
\end{table}

\subsection{Consumo eléctrico de la consola portátil}
La consola está alimentada íntegramente desde una powerbank 12000\,mAh (capacidad nominal 12\,Wh @ 5V). En la Tabla~\ref{tab:consumo} se desglosa el consumo de cada componente y el tiempo de autonomía estimado.

\begin{table}[H]
\centering
\caption{Presupuesto de consumo eléctrico de la consola portátil.}
\label{tab:consumo}
\footnotesize
\begin{tabular}{@{}llccccl@{}}
\toprule
\textbf{Componente} & \textbf{Tipo} & \textbf{Voltaje} & \textbf{Corriente} & \textbf{Potencia} & \textbf{Duty} & \textbf{Notas} \\
\midrule
ESP32 (WiFi + core) & MCU & 3.3\,V & 80\,mA & 0.26\,W & 100\,\% & WiFi activo \\
OLED 128x64 & Display & 3.3\,V & 20\,mA & 0.07\,W & 100\,\% & Brillo normal \\
Botones (pull-ups) & Digital & 3.3\,V & 5\,mA & 0.02\,W & 100\,\% & 4 resistencias 10\,k \\
\midrule
\textbf{Total ESP32} & & & \textbf{105\,mA} & \textbf{0.35\,W} & & \\
\midrule
DC-DC Regulador & Boost 5V→3.3V & 5\,V & 63\,mA & 0.32\,W & 91\,\% & Eficiencia típica \\
\midrule
\textbf{Consumo Total} & & \textbf{5V} & \textbf{168\,mA} & \textbf{0.84\,W} & & \\
\midrule
\multicolumn{7}{c}{\textit{Autonomía con powerbank 12000\,mAh @ 5V nominal:}} \\
\multicolumn{7}{c}{\textit{Tiempo = 12000\,mAh / 168\,mA $\approx$ 71 horas (continuo)}} \\
\multicolumn{7}{c}{\textit{Operación típica ($\sim$8 horas/turno): Múltiples turnos sin recarga}} \\
\bottomrule
\end{tabular}
\end{table}

En la práctica, el consumo puede variar: modo profundo (light sleep) reduce a $\sim$10\,mA; actividad de botones es esporádica. La powerbank ofrece \textbf{autonomía de 2--3 días de operación típica} (8 horas/día).

\subsection{Concurrencia con FreeRTOS: disparo no bloqueante de servomotores}
El patrón embebido más relevante del proyecto resuelve RF-04. Cuando llega \texttt{fruta/estado=rechazada}, el \emph{callback} de MQTT \textbf{no} gira los servomotores directamente (eso lo bloquearía 350\,ms), sino que \emph{notifica} a una tarea dedicada mediante \texttt{xTaskNotifyGive}; la tarea mueve los servos, espera con \texttt{vTaskDelay} y publica la confirmación, todo sin congelar el hilo de red. El Código~\ref{lst:servos} muestra esta tarea.

\begin{lstlisting}[style=C, caption={Tarea FreeRTOS de los servomotores: espera una notificación, gira a 180°, retorna a neutral y confirma por MQTT, sin bloquear el hilo del broker.}, label={lst:servos}]
static void tarea_servos_expulsion(void *arg) {
    while (1) {
        // Bloquea aquí hasta recibir xTaskNotifyGive() desde el callback MQTT
        ulTaskNotifyTake(pdTRUE, portMAX_DELAY);

        ESP_LOGI(TAG, ">>> Disparando servomotores a 180 grados");
        servo_set_angle(1, 180);    // Servo 1 abre (180°)
        servo_set_angle(2, 180);    // Servo 2 abre (180°)
        
        vTaskDelay(pdMS_TO_TICKS(300));      // Mantener 300 ms
        
        servo_set_angle(1, 90);     // Servo 1 retorna a neutral (90°)
        servo_set_angle(2, 90);     // Servo 2 retorna a neutral (90°)
        
        vTaskDelay(pdMS_TO_TICKS(50));       // Estabilización

        ESP_LOGI(TAG, ">>> Servomotores retornados a neutral");

        if (cliente_mqtt)
            esp_mqtt_client_publish(cliente_mqtt, TOPIC_SERVOS, "expulsado", 0, 1, 0);
    }
}
\end{lstlisting}

El \emph{callback} de MQTT del nodo Motor interpreta los tópicos suscritos y solo dispara cuando el sistema está activo, como muestra el Código~\ref{lst:mqtt}.

\begin{lstlisting}[style=C, caption={Manejo de eventos MQTT en el nodo Motor (caso de datos recibidos con servomotores).}, label={lst:mqtt}]
if (strcmp(topic, TOPIC_COMANDO) == 0) {
    if (strcmp(data, "iniciar") == 0) {
        sistema_activo = true;  motor_avanzar(MOTOR_VEL_NORMAL);
        esp_mqtt_client_publish(client, TOPIC_MOTOR, "activo", 0, 1, 0);
    } else if (strcmp(data, "detener") == 0) {
        sistema_activo = false; motor_detener();
        esp_mqtt_client_publish(client, TOPIC_MOTOR, "detenido", 0, 1, 0);
    }
}
else if (strcmp(topic, TOPIC_FRUTA) == 0 && sistema_activo) {
    if (strcmp(data, "rechazada") == 0)
        xTaskNotifyGive(tarea_servos_handle);   // NOTIFICA a la tarea, no bloquea
}
\end{lstlisting}

\subsection{Máquinas de estados finitos (FSM) actualizadas}

El comportamiento de cada nodo se modela como una máquina de estados finitos. La Figura~\ref{fig:fsmmotor} presenta la FSM del nodo Motor actualizada con servomotores: tras el arranque conecta WiFi y MQTT, y alterna entre \texttt{DETENIDO} y \texttt{ACTIVO} según los comandos; en \texttt{ACTIVO}, un veredicto \texttt{rechazada} dispara los servomotores.

\begin{figure}[H]
  \centering
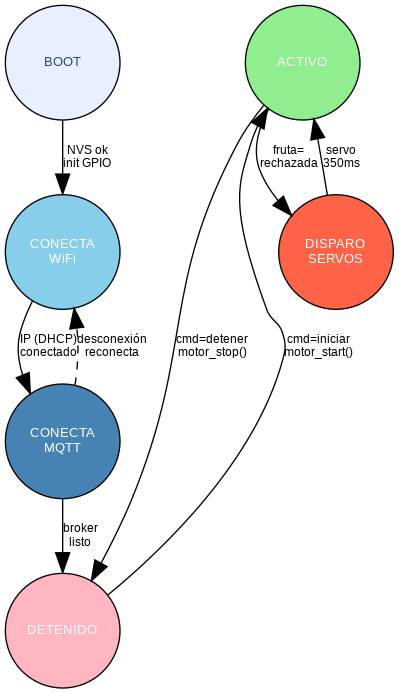
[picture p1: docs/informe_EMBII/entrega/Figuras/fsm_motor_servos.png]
  
  \caption{FSM del nodo ESP32 Motor actualizada con servomotores MG996R. El estado \texttt{DISPARO SERVOS} se ejecuta en una tarea FreeRTOS separada (no bloqueante, duración total 350\,ms).}
  \label{fig:fsmmotor}
\end{figure}

La Figura~\ref{fig:fsmconsola} muestra la FSM de navegación de pantallas de la consola: el botón PANTALLA rota entre \texttt{CONTADORES}, \texttt{DIAGNÓSTICO} y \texttt{ALERTA}; tres rechazos consecutivos fuerzan el salto a \texttt{ALERTA} y lo muestran en pantalla OLED; el botón RESET limpia contadores y alerta.

\begin{figure}[H]
  \centering
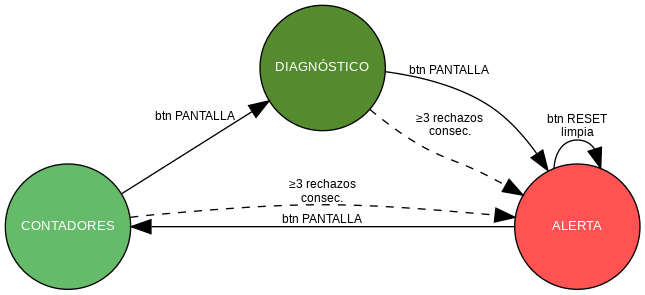
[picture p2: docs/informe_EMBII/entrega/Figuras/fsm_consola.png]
  
  \caption{FSM de pantallas de la consola OLED. La transición forzada a \texttt{ALERTA} se dispara con tres rechazos consecutivos.}
  \label{fig:fsmconsola}
\end{figure}

% ====================================================================
\section{Caracterización y gráficas de respuesta}
\label{sec:respuestas}
% ====================================================================

\subsection{Señal PWM del motor}
El periférico LEDC genera la señal PWM a \SI{10}{\kilo\hertz} sobre \texttt{RPWM} (GPIO25). Con \texttt{MOTOR\_VEL\_NORMAL=150} sobre 255, el ciclo de trabajo es del 58.8\,\%, como se observa en la Figura~\ref{fig:pwm}. La Figura~\ref{fig:ledc} muestra la relación lineal entre el valor de \emph{duty} (8 bits) y la tensión media aplicada al motor, y el punto de operación elegido.

\begin{figure}[H]
  \centering
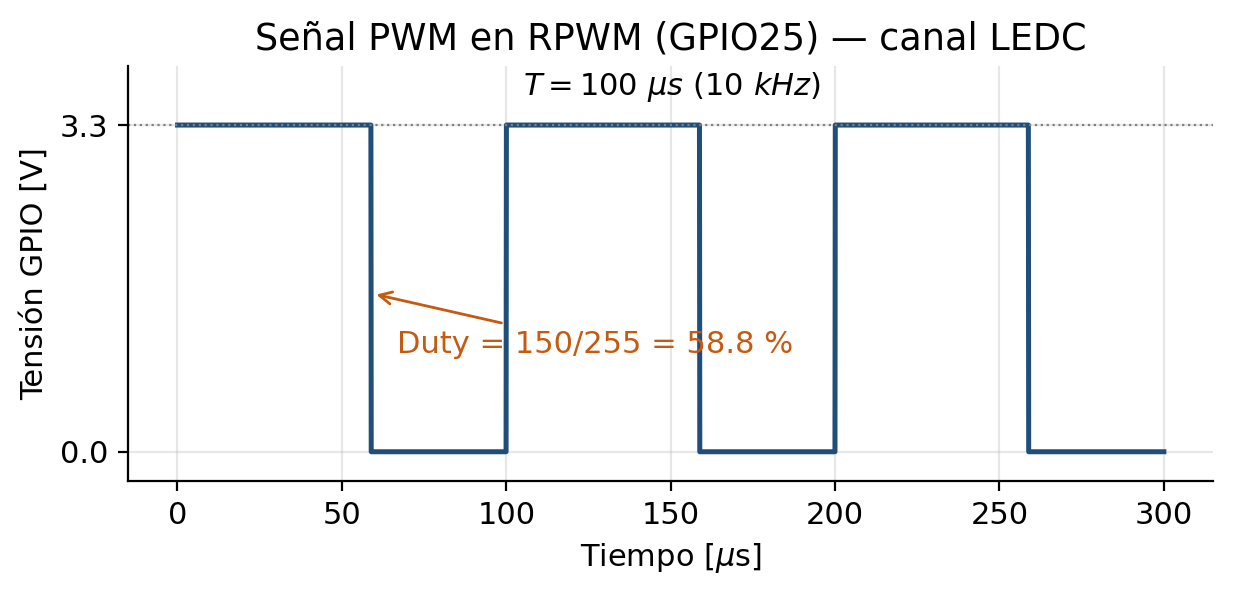
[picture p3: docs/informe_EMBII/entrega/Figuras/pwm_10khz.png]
  
  \caption{Señal PWM a 10 kHz en GPIO25 con ciclo de trabajo de 150/255 (58.8\,\%). Período de \SI{100}{\micro\second}.}
  \label{fig:pwm}
\end{figure}

\begin{figure}[H]
  \centering
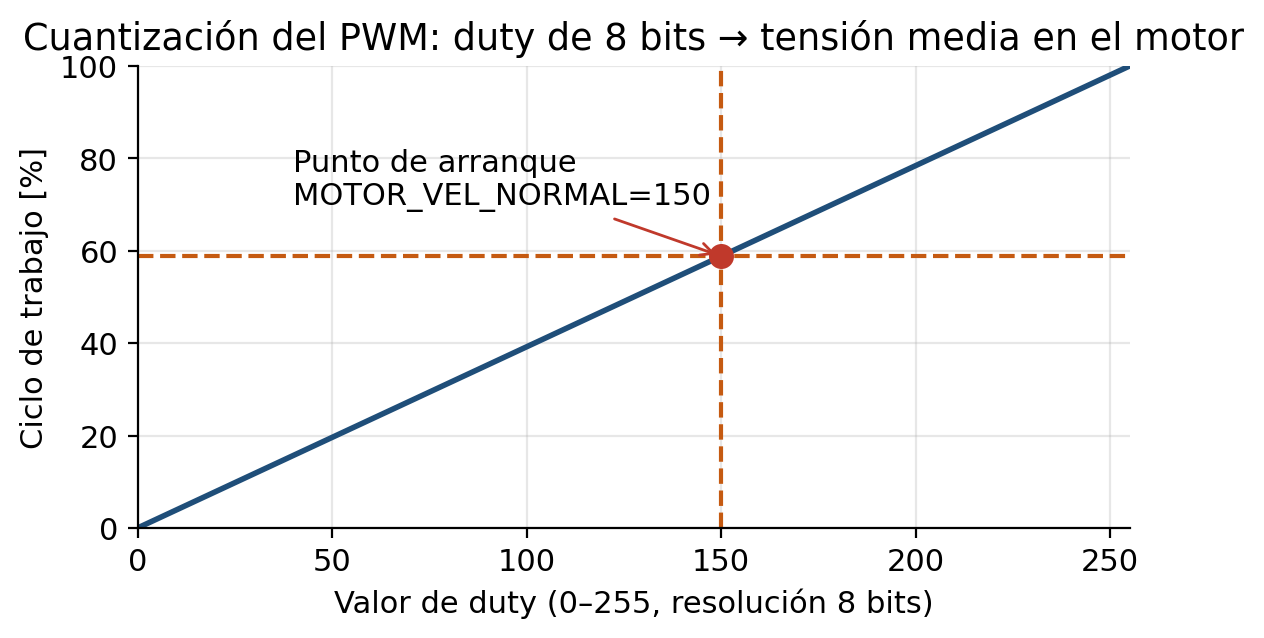
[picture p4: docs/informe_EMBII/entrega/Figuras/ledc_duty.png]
  
  \caption{Cuantización del PWM: el \emph{duty} de 8 bits se mapea linealmente a la tensión media en el motor. En rojo, el punto de arranque (\emph{duty}=150).}
  \label{fig:ledc}
\end{figure}

La Figura~\ref{fig:pwm} es una representación a partir de los parámetros de configuración; en la defensa debe acompañarse de una \textbf{captura real de osciloscopio} sobre GPIO25 (ver Figura~\ref{fig:osc}).

\begin{figure}[H]
  \centering
  \fotopendiente[5.5cm]{Captura de osciloscopio de la señal PWM en GPIO25 (medir frecuencia $\approx$10 kHz y ciclo de trabajo).}
  \caption{Captura real de osciloscopio de la señal PWM (a incorporar).}
  \label{fig:osc}
\end{figure}

\subsection{Cronograma del disparo de servomotores}
La Figura~\ref{fig:cronoval} muestra la temporización del disparo no bloqueante: el evento MQTT \texttt{rechazada} provoca el giro de los servomotores (GPIO4, GPIO5) desde 90° a 180° durante \texttt{SERVO\_MS=300\,ms}; los servos actúan mecánicamente y, al retornar a neutral, el nodo publica \texttt{sistema/servos=expulsado}.

\begin{figure}[H]
  \centering
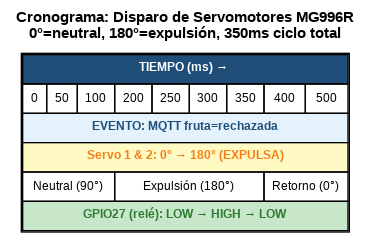
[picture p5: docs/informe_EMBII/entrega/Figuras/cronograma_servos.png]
  
  \caption{Cronograma del disparo de servomotores gestionado por la tarea FreeRTOS dedicada. Incluye rampas de giro y estabilización.}
  \label{fig:cronoval}
\end{figure}

\subsection{Presupuesto de latencia extremo a extremo}
La Figura~\ref{fig:lat} descompone el tiempo total desde la captura hasta la expulsión. La etapa dominante es la inferencia de visión en la PC; las etapas de red y reacción embebida suman pocas decenas de milisegundos, de modo que el total se mantiene holgadamente por debajo de los 2\,s (RNF-01) y determina la velocidad máxima admisible de la banda.

\begin{figure}[H]
  \centering
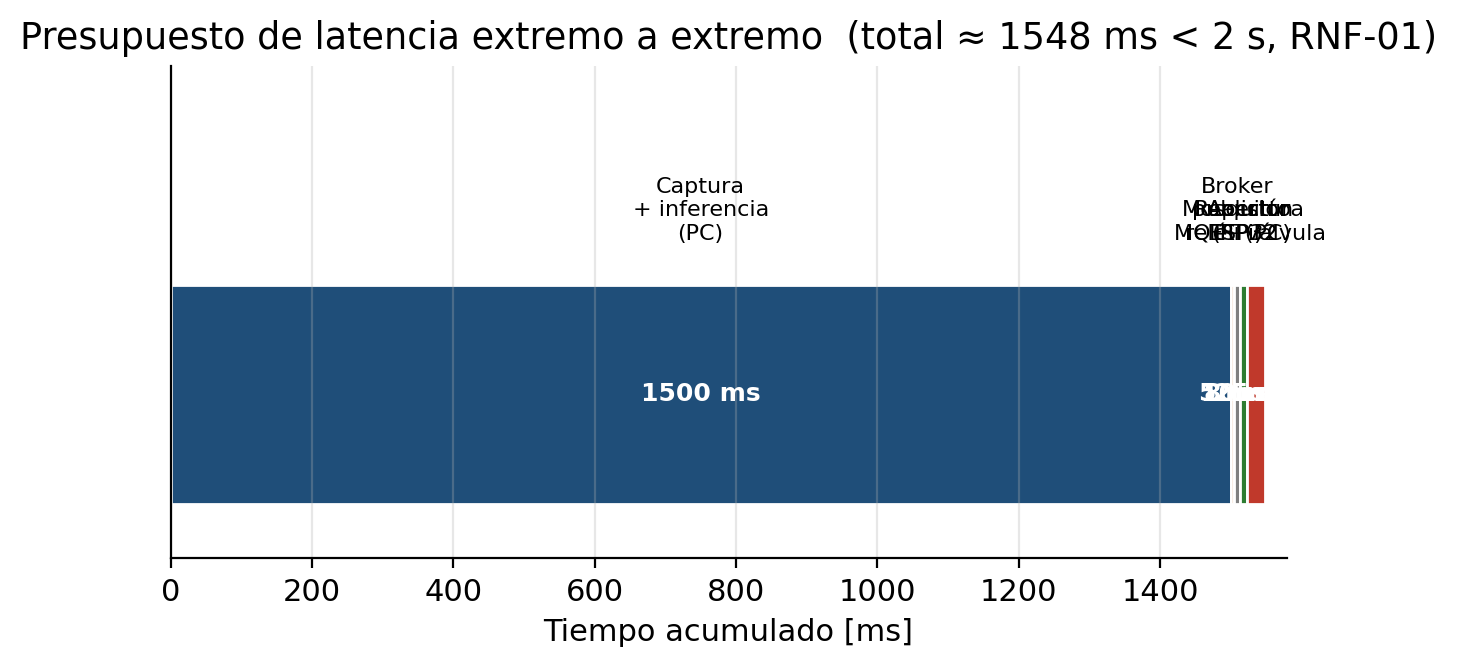
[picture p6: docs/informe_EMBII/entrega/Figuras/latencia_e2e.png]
  
  \caption{Presupuesto de latencia extremo a extremo (valores típicos/de especificación). La inferencia domina; la cadena MQTT + reacción embebida es despreciable frente a ella.}
  \label{fig:lat}
\end{figure}

% ====================================================================
\section{Aplicación real: producción de tomate en Tarija}
\label{sec:tarija}
% ====================================================================

El fin último de la cinta es servir como herramienta de control de calidad poscosecha accesible a pequeños productores de tomate. Tarija reúne condiciones idóneas: pese a ser el departamento más pequeño de Bolivia, dispone de unas 189.268 hectáreas con vocación productiva agrícola \cite{eldiario2026potencial}, y el tomate es uno de los cultivos relevantes de sus valles \cite{elpais2023aviles}.

\paragraph{Comunidad propuesta: Chocloca (municipio de Uriondo, Valle Central).} Se propone como caso de aplicación la comunidad de \textbf{Chocloca}, uno de los nueve distritos del municipio de Uriondo (provincia José María Avilés), a unos 25\,km al sur de la ciudad de Tarija, en el Valle Central. El municipio agrupa 53 comunidades campesinas, de las cuales más del 90\,\% se dedica a la agricultura, con el tomate entre sus principales cultivos junto a la vid, la papa y el morrón \cite{elpais2023aviles}. Chocloca pertenece a la cuenca del río Camacho, de clima templado (temperatura media diaria máxima cercana a 26\,°C y precipitación media anual en torno a 740\,mm) \cite{erazo2003totora,wiki_uriondo}, lo que favorece varias campañas hortícolas al año.

\paragraph{Por qué es un caso idóneo.} Varios factores hacen pertinente el prototipo en esta comunidad:
\begin{itemize}
  \item \textbf{Clasificación manual y pérdidas.} La selección del tomate se hace a mano; un fruto deteriorado no detectado contamina el resto del lote, generando pérdidas.
  \item \textbf{Vulnerabilidad de la oferta.} La producción de tomate en Tarija llegó a caer hasta un 60\,\% por sequías y heladas; en un contexto de oferta ajustada, reducir el descarte tiene impacto económico directo.
  \item \textbf{Contexto rural sin Internet.} La arquitectura del proyecto opera sobre una red WiFi local autónoma (RPi como Access Point) y una consola a batería; no requiere conectividad externa (RNF-05).
\end{itemize}

% ====================================================================
\section{Anexo: material gráfico a incorporar}
% ====================================================================

Las figuras generadas (diagrama de bloques, secuencia MQTT, FSMs y gráficas de respuesta) ya están incluidas. Para completar la memoria con evidencia del prototipo real, se recomienda incorporar las siguientes \textbf{fotografías/capturas}, guardándolas en \texttt{./Figuras/} y reemplazando los recuadros reservados:

\begin{enumerate}
  \item \textbf{Montaje general} de la banda con 3 cámaras, zona de visión y zona de desvío (vista lateral y cenital).
  \item \textbf{Nodo ESP32 Motor} cableado al BTS7960 y servomotores MG996R (mostrar tierra común).
  \item \textbf{Captura de osciloscopio} de la señal PWM en GPIO25 (Figura~\ref{fig:osc}): verificar 10\,kHz y \emph{duty} 58.8\,\%.
  \item \textbf{Consola portátil} encendida mostrando la pantalla OLED con contadores.
  \item \textbf{Monitor serial} del ESP32 mostrando ``IP obtenida'' y ``Conectado al broker''.
  \item \textbf{Secuencia de expulsión}: foto de los servomotores desviando un tomate rechazado.
  \item \textbf{Tomates reales} de la zona usados en la prueba (sanos y deteriorados), idealmente de Chocloca/Uriondo.
\end{enumerate}

% --- Bibliografía APA 7ma ---
\newpage
\printbibliography[heading=bibintoc, title={Referencias Bibliográficas}]

\end{document}

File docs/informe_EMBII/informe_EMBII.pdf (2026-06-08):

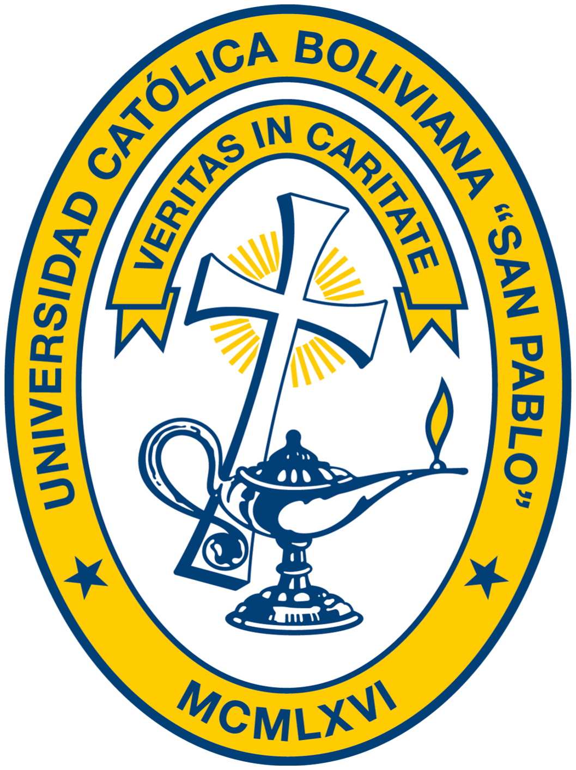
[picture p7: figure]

Universidad Católica Boliviana "San Pablo"

Departamento de Ciencias de la Tecnología e Innovación

Ingeniería Mecatrónica

# Sistema Automático de Clasificación de Tomates mediante Visión Artificial y ESP32

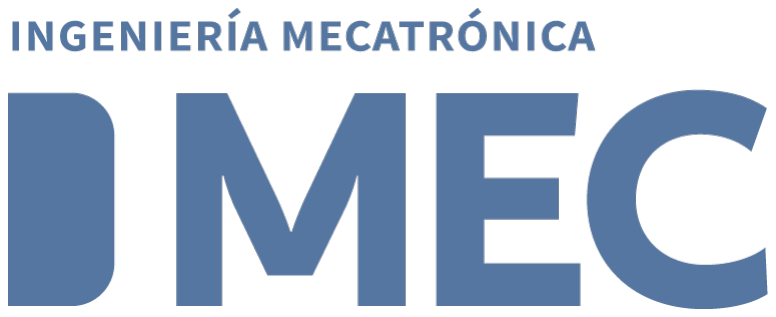
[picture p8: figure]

### Materia: Sistemas Embebidos II

Estudiante(s): Susann Baldiviezo C. Alejandro Bejarano R.
Florencia Frigerio A.
Benjamín Soruco G.
Docente: Msc. Ing. Alan Cornejo Q.

### Semestre: 1/2026

### Bolivia, 8 de junio de 2026

2

## Índice

1. Descripción técnica-conceptual del proyecto a realizar | 1
2. Propósito del proyecto | 2
3. Alcance del proyecto | 3
4. Supuestos del proyecto | 4
5. Requerimientos | 4
6. Entregables principales del proyecto | 7
7. Fundamentos teóricos (conocimientos básicos) | 7
8. Arquitectura de comunicaciones y protocolos | 8
9. Diseño del firmware embebido | 10
9.4. Concurrencia con FreeRTOS: disparo no bloqueante de servomotores . . . . | 11
10.Caracterización y gráficas de respuesta | 14
11.Aplicación real: producción de tomate en Tarija | 17
Referencias Bibliográficas | 19

## Índice de figuras

1. Diagrama en bloques del sistema actualizado con servomotores MG996R.
La Raspberry Pi actúa como concentrador de mensajería (broker MQTT)
y punto de acceso WiFi; los nodos se comunican de forma indirecta a través
de tópicos[cite: 189, 190, 191] | 2
2. Diagrama de secuencia MQTT para el arranque (comando del operario) y para un fruto rechazado. El broker desacopla a los nodos y replica cada
mensaje a los suscriptores[cite: 268, 269] | 9
3. FSM del nodo ESP32 Motor actualizada con servomotores MG996R. El estado DISPARO SERVOS se ejecuta en una tarea FreeRTOS separada (no
bloqueante, duración total 350 ms)[cite: 296, 297] | 13
4. FSM de pantallas de la consola OLED. La transición forzada a ALERTA se
dispara con tres rechazos consecutivos[cite: 299, 300] | 14
5. Señal PWM a 10 kHz en GPIO25 con ciclo de trabajo de 150/255 (58.8 %).
Período de 100 ţs[cite: 303, 304] | 15
6. Cuantización del PWM: el duty de 8 bits se mapea linealmente a la tensión media en el motor. En rojo, el punto de arranque (duty=150)[cite: 304, 305]. 15
7. Cronograma del disparo de servomotores gestionado por la tarea FreeRTOS
dedicada. Incluye rampas de giro y estabilización[cite: 309, 310] | 16
8. Presupuesto de latencia extremo a extremo (valores típicos/de especificación). La inferencia domina; la cadena MQTT + reacción embebida es des-
preciable frente a ella[cite: 313, 314] | 17

## Índice de tablas

1. | Componentes de hardware del sistema (actualizado con servomotores). . . | 6
2. | Software, frameworks y bibliotecas | | 6
3. | Entregables del proyecto | | 7
4. | Parámetros de la red local del sistema | | 8
5. | Tópicos MQTT, publicadores, suscriptores y cargas útiles (payloads). . . . | 9
6. | Pinout del ESP32 Motor (driver BTS7960 + servomotores MG996R). . . . | 10
7. | Pinout del ESP32 Consola (OLED I²C, botones) | | 10
8. | Presupuesto de consumo eléctrico de la consola portátil | | 11

## 1. Descripción técnica-conceptual del proyecto a realizar

El proyecto consiste en el diseño e implementación de un sistema automático de clasificación de tomates sobre una banda transportadora, que separa físicamente los frutos en buen estado de aquellos en estado de descomposición[cite: 169]. La detección se realiza por visión artificial con OpenCV Gonzalez y Woods, 2018; OpenCV Development Team, 2024, mientras que toda la cadena de control, actuación, comunicación y monitoreo se resuelve con sistemas embebidos basados en el microcontrolador ESP32 Espressif Systems, 2023, que constituyen el núcleo de este documento[cite: 170]. El sistema se organiza en cuatro capas: (i) adquisición, con cámaras USB sobre la banda[cite: 171]; (ii) procesamiento, en una PC que ejecuta el algoritmo de visión[cite: 172]; (iii) mensajería, en una Raspberry Pi que actúa como broker MQTT Light, 2017 y punto de acceso WiFi [cite: 173]; y (iv) actuación y monitoreo, con dos ESP32 independientes: uno controla el motor de la banda y dos servomotores MG996R para desvío, y el otro es una consola portátil inalámbrica para el operario[cite: 174]. La PC emite un veredicto binario por cada fruto (aceptada o rechazada) y lo publica en la red [cite: 175]; los nodos embebidos reaccionan a ese mensaje en tiempo real[cite: 176].

El principal desafío técnico no está en la visión, sino en la coordinación distribuida en tiempo real entre nodos heterogéneos sin un cableado punto a punto: tres equipos (PC y dos ESP32) deben compartir estado de forma confiable, con baja latencia y de manera robusta ante desconexiones, sobre una red local que además debe funcionar sin acceso a Internet[cite: 177]. La propuesta de valor es ofrecer una solución de control de calidad poscosecha automatizada, portátil y de bajo costo, reproducible con componentes disponibles en el mercado local, orientada a pequeños productores (Sección 11)[cite: 178]. En la Figura 1 se presenta el diagrama en bloques del sistema[cite: 179]. Se observa la separación en capas y, en particular, que la Raspberry Pi concentra la mensajería: ningún nodo se comunica directamente con otro, sino que todos publican y se suscriben a través del broker, lo que desacopla a los dispositivos entre sí[cite: 180].

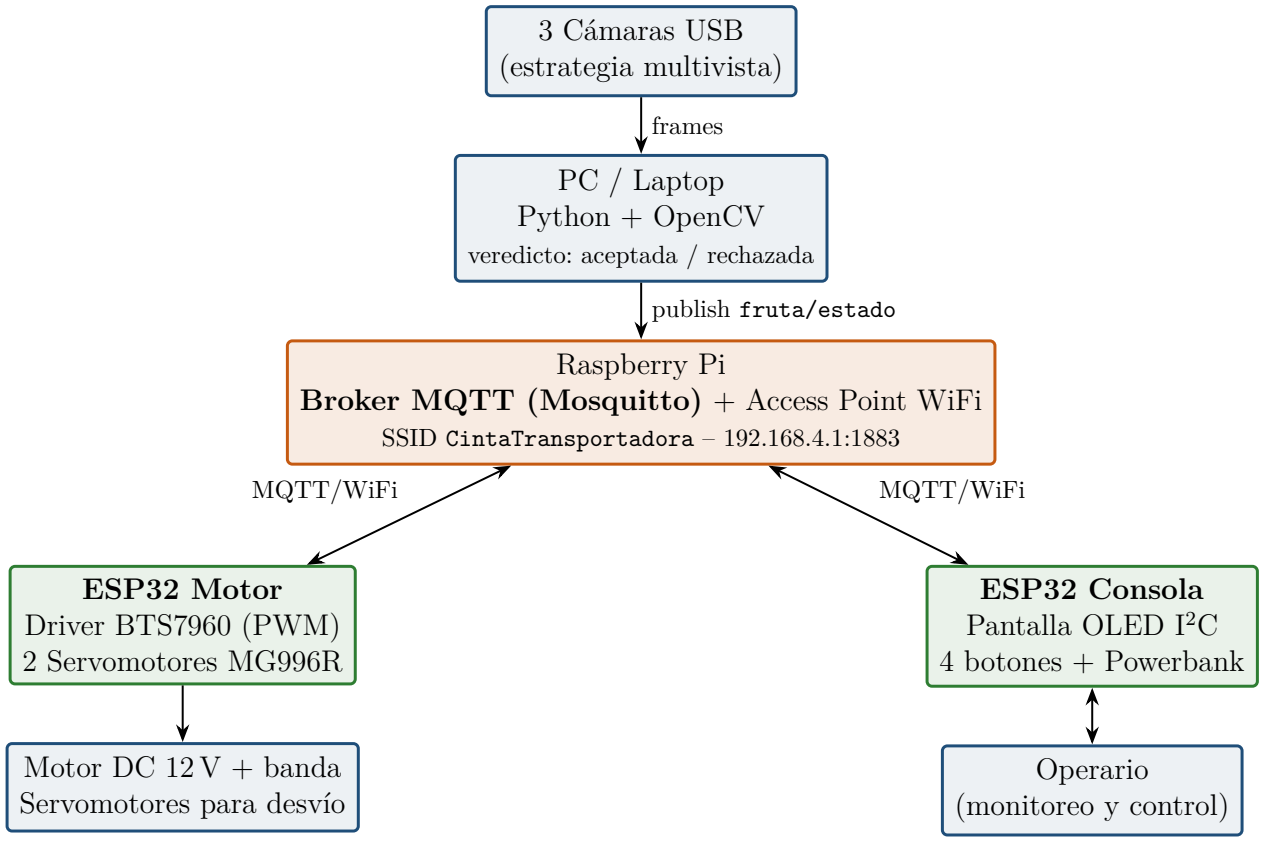
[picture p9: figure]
3 Cámaras USB (estrategia multivista); PC / Laptop Python + OpenCV; veredicto: aceptada / rechazada; Raspberry Pi; SSID CintaTransportadora – 192.168.4.1:1883; ESP32 Motor Driver BTS7960 (PWM) 2 Servomotores MG996R; ESP32 Consola Pantalla OLED I²C; 4 botones + Powerbank; Motor DC 12 V + banda Servomotores para desvío; Operario (monitoreo y control); frames; publish fruta/estado; MQTT/WiFi

Broker MQTT (Mosquitto) + Access Point WiFi

Figura 1: Diagrama en bloques del sistema actualizado con servomotores MG996R. La Raspberry Pi actúa como concentrador de mensajería (broker MQTT) y punto de acceso WiFi; los nodos se comunican de forma indirecta a través de tópicos[cite: 189, 190, 191].

## 2. Propósito del proyecto

El propósito es automatizar la clasificación poscosecha de tomate por estado de sanidad (sano vs. deteriorado), integrando visión artificial con un sistema embebido distribuido que controle los actuadores y permita la supervisión del operario en tiempo real[cite: 191]. En concreto se busca:

Reducir la intervención humana en una tarea repetitiva y con alto margen de error visual, separando automáticamente el fruto deteriorado[cite: 192].

Disminuir las pérdidas económicas asociadas a la comercialización de fruto en mal estado y al contagio de la podredumbre dentro del lote[cite: 193].

Demostrar la viabilidad técnica de coordinar varios nodos embebidos ESP32 con una PC mediante un protocolo de mensajería liviano (MQTT) sobre una red WiFi local autónoma[cite: 194].

Aplicar de forma integrada los contenidos de Sistemas Embebidos II: GPIO, PWM, I

2C, conectividad WiFi, multitarea con FreeRTOS Barry, 2016 y control de actuadores de potencia[cite: 195].

Desde lo académico, el énfasis está en el firmware embebido y la arquitectura de comunicaciones; la visión artificial se trata como un módulo proveedor de veredictos cuya implementación interna es intercambiable[cite: 196, 197].

## 3. Alcance del proyecto

El proyecto abarca el diseño, la construcción y la validación de un prototipo funcional[cite: 198]. A continuación se delimita el alcance.

### 3.1. Lo que el sistema SÍ contempla

Firmware embebido para dos ESP32 desarrollado sobre ESP-IDF v5.x Espressif Systems, 2024: control de motor por PWM, disparo de servomotores, lectura de botones y manejo de display OLED[cite: 199].

Control de la banda transportadora mediante driver de potencia BTS7960 (puente
H) Infineon Technologies, 2004[cite: 200].

Expulsión física del fruto rechazado mediante dos servomotores MG996R acoplados mecánicamente con precisión angular de ±5[cite: 201].

Arquitectura de comunicaciones completa: red WiFi local con la Raspberry Pi como Access Point y broker MQTT, definición de tópicos, calidad de servicio y secuencia de mensajes[cite: 202].

Consola portátil (segunda ESP32) con pantalla OLED I²C (128x64 px), cuatro botones, alimentada por powerbank 12000 mAh, para monitoreo y control inalámbrico[cite: 203].

Clasificación binaria: buen estado / mal estado, bajo iluminación controlada de laboratorio[cite: 204].

### 3.2. Lo que el sistema NO contempla

El presente proyecto no incluye:

Clasificación por tamaño, peso o grado de madurez (solo estado de descomposición)[cite: 205].

Operación en líneas industriales de alta velocidad o con varios tipos de fruta en simultáneo[cite: 206].

Seguridad/cifrado de la red MQTT (se asume red local privada y aislada)[cite: 207].

Integración con sistemas ERP o trazabilidad industrial[cite: 208].

## 4. Supuestos del proyecto

Para el desarrollo del proyecto se supone que:

Iluminación controlada: el prototipo opera bajo luz artificial constante que minimiza variaciones que afecten el análisis de color y textura[cite: 208].

Frutos individualizados: los tomates se colocan sobre la banda separados entre sí, de modo que el sistema los analice de forma independiente[cite: 209].

Velocidad de banda calibrada: la velocidad es fija (14 segundos entre estaciones)
y permite a la visión capturar y procesar cada fruto a tiempo (Sección 10)[cite: 210].

Red WiFi local disponible: la Raspberry Pi genera el Access Point CintaTransportadora; no se requiere Internet[cite: 211].

Tierra común: todos los GND (ESP32, BTS7960, fuente 12 V, servomotores) están unidos; sin ello el sistema se comporta de forma errática[cite: 212, 213].

Ambiente de laboratorio: el prototipo se diseña para taller académico, no para entornos con polvo, humedad o vibración industrial[cite: 213].

## 5. Requerimientos

### 5.1. Requerimientos funcionales

1. Sistema principal de clasificación:
a) RF-01: el sistema debe capturar imágenes de cada fruto y emitir un veredicto binario[cite: 214].
b) RF-02: la ESP32 Motor debe arrancar/detener la banda según el comando del operario[cite: 215].
c) RF-03: ante un veredicto rechazada, la ESP32 Motor debe disparar los servomotores y expulsar el fruto[cite: 216].
d) RF-04: el disparo de los servomotores no debe bloquear la atención de nuevos mensajes MQTT[cite: 217].
2. Consola portátil del operario:
a) RF-05: la consola debe mostrar contadores de aceptadas/rechazadas y el estado del motor con latencia menor a 1 s[cite: 218].

b) RF-06: el operario debe poder iniciar y detener todo el proceso desde la consola, sin acceder a la PC[cite: 219].
c) RF-07: la consola debe indicar mediante pantalla OLED un volumen elevado de rechazos consecutivos[cite: 220].
d) RF-08: la consola debe indicar la pérdida de conexión con el sistema central[cite: 221].
e) RF-09: la consola debe funcionar de forma autónoma (powerbank), sin cables[cite: 222].

### 5.2. Requerimientos no funcionales

1. RNF-01: el tiempo de procesamiento y reacción por fruto no debe superar los 2 s[cite: 223].
2. RNF-02: el sistema debe operar de forma continua al menos 30 min sin fallos[cite: 224].
3. RNF-03: el firmware debe estar estructurado de forma modular y documentado[cite: 225].
4. RNF-04: el prototipo debe ser reproducible con componentes de bajo costo del mercado local[cite: 226].
5. RNF-05: el sistema debe operar sin acceso a Internet (red local autónoma)[cite: 227].

### 5.3. Requerimientos de hardware

En la Tabla 1 se listan los componentes de hardware[cite: 228]. En la Tabla 2 se listan las herramientas y bibliotecas de software con sus versiones[cite: 229].

Tabla 1: Componentes de hardware del sistema (actualizado con servomotores).

ID | Componente | Cant.
H-01 | ESP32 WROOM-32 (nodo Motor) | 1
H-02 | ESP32 WROOM-32 (nodo Consola) | 1
H-03 | Raspberry Pi (broker MQTT + Access Point) | 1
H-04 | Driver BTS7960 / IBT-2 (puente H) | 1
H-05 | Motor DC 12 V + banda transportadora | 1
H-06 | Servomotor MG996R | 2
H-07 | Fuente 12 V (motor + servos) | 1
H-08 | 3 cámaras USB | 3
H-09 | PC / Laptop (procesamiento OpenCV) | 1
H-10 | Pantalla OLED I²C 128x64 px (SSD1306) | 1
H-11 | 4 pulsadores (botones) | 4
H-12 | Powerbank 5 V 12000 mAh (alimentación consola) | 1
H-13 | Iluminación LED controlada | 1

Tabla 2: Software, frameworks y bibliotecas.

Componente | Rol | Versión
ESP-IDF | Framework de desarrollo ESP32 | v5.0+
FreeRTOS | RTOS (multitarea) incluido en ESP-IDF | —
espressif/mqtt | Cliente MQTT del ESP32 | IDF v5.x
Mosquitto | Broker MQTT (Raspberry Pi) | 2.x
NetworkManager (nmcli) | Access Point WiFi en la RPi | —
Python | Módulo de visión y simulador | 3.10+
OpenCV | Visión por computadora | 4.8+
paho-mqtt | Cliente MQTT en Python | 1.6+

## 6. Entregables principales del proyecto

Tabla 3: Entregables del proyecto.

Entregable | Descripción
Prototipo físico | Banda con 3 cámaras, servomotores y nodos ESP32
integrados y funcionando[cite: 232].
Firmware ESP32 Motor | Código embebido modular (motor, servomotores,
MQTT, WiFi) sobre ESP-IDF[cite: 233]. Firmware ESP32 Consola Código de la consola portátil (OLED, botones, MQTT)[cite: 234].
Configuración Raspberry
Pi
Broker | Mosquitto, | Access | Point | y | servicio
systemd[cite: 235].
Esquemas y pinouts | Conexiones de hardware y diagramas (Secciones 9–
10)[cite: 236].
Memoria del trabajo final El presente documento Universidad Católica Boliviana "San Pablo", 2026[cite: 236].
Demostración en vivo | Sistema funcionando con tomates reales ante el do-
cente[cite: 237].

## 7. Fundamentos teóricos (conocimientos básicos)

ESP32 y FreeRTOS. El ESP32 es un SoC con doble núcleo Xtensa LX6, WiFi 802.11 b/g/n y Bluetooth integrados Espressif Systems, 2023[cite: 238]. El framework ESP-IDF lo programa en C sobre FreeRTOS, un kernel de tiempo real que permite ejecutar varias tareas concurrentes con planificación por prioridades Barry, 2016[cite: 239]. Esto es clave en el proyecto: una operación que tarda (girar los servomotores 350 ms) se delega a una tarea propia para no bloquear la atención de la red[cite: 240].

GPIO y PWM (periférico LEDC). Los pines de propósito general (GPIO) leen botones[cite: 241]. Para regular la velocidad del motor se usa PWM (modulación por ancho de pulso): el periférico LEDC del ESP32 genera una onda cuadrada de frecuencia fija (10 kHz) cuyo ciclo de trabajo (duty, 0–255 en resolución de 8 bits) fija la tensión media aplicada al motor a través del BTS7960[cite: 242]. Los servomotores se controlan con PWM a 50 Hz con ancho de pulso variable (1.0–2.0 ms para 0ř–180ř)[cite: 243].

Puente H BTS7960. Es un medio puente de alta corriente; dos integrados forman un puente H completo (módulo IBT-2) capaz de manejar el motor DC de 12 V, con entradas RPWM/LPWM para sentido/velocidad y R_EN/L_EN para habilitación Infineon Technologies, 2004[cite: 244, 245].

Servomotor MG996R. Servomotor de torque alto (11 kgůcm a 6 V), velocidad 0.2 s/60ř y rango 0ř–180ř. Se controla mediante PWM a 50 Hz; el ancho de pulso (1.0–2.0 ms) determina la posición angular[cite: 246]. Dos servos acoplados mecánicamente permiten expulsar frutos rechazados con precisión y retornar a posición neutral[cite: 247].

I

2C y pantalla OLED. La pantalla OLED 128x64 px (controlador SSD1306) se comunica por I2C a 100 kHz (dirección típica 0x3C), con solo dos pines (SDA y SCL)[cite: 248]. Ofrece mejor visibilidad que LCD, bajo consumo de corriente (20 mA típico) y funcionamiento con batería[cite: 249].

WiFi (modos STA y AP). Cada ESP32 opera como estación (STA) y se asocia al Access Point creado por la Raspberry Pi (modo AP)[cite: 250]. Así se forma una red local cerrada, sin router ni Internet IEEE, 2021[cite: 251].

MQTT. Protocolo de mensajería publicación/suscripción liviano sobre TCP, ideal para IoT Banks y Gupta, 2014[cite: 252]. Un broker (Mosquitto) recibe mensajes publicados en tópicos y los reenvía a los clientes suscritos[cite: 253]. La calidad de servicio QoS 1 garantiza “al menos una entrega”[cite: 254]. Este desacople publicador/suscriptor es lo que permite agregar o quitar nodos sin reconfigurar a los demás[cite: 255].

## 8. Arquitectura de comunicaciones y protocolos

Esta es la columna vertebral del sistema[cite: 256]. La PC y los dos ESP32 no se comunican entre sí directamente: todos lo hacen a través del broker MQTT alojado en la Raspberry Pi[cite: 257].

### 8.1. Topología de red

La Raspberry Pi crea un Access Point WiFi WPA2 (canal 7, banda 2.4 GHz) mediante nmcli, con IP fija 192.168.4.1, y los clientes obtienen IP por DHCP[cite: 258]. En la Tabla 4 se resumen los parámetros de red.

Tabla 4: Parámetros de la red local del sistema.
Parámetro | Valor
SSID | CintaTransportadora
Seguridad | WPA2-PSK (clave cinta2026)
Banda / canal | 2.4 GHz / 7
IP del broker (RPi, AP) | 192.168.4.1
Puerto MQTT | 1883 (TCP)
Asignación de IP a clientes | DHCP (192.168.4.x)
Autenticación del broker | anónima (allow_anonymous true)

### 8.2. Tópicos MQTT

La Tabla 5 define el contrato de communication: cada tópico, quién publica, quién se suscribe y los valores válidos[cite: 259]. Todos los mensajes se intercambian con QoS 1[cite: 260].

Tabla 5: Tópicos MQTT, publicadores, suscriptores y cargas útiles (payloads).

Tópico | Publica | Se suscribe | Valores
fruta/estado | PC (OpenCV) | ESP32 Motor, Consola | aceptada, rechazada
operario/comando | ESP32 Consola | ESP32 Motor | iniciar, detener
sistema/motor | ESP32 Motor | ESP32 Consola | activo, detenido, esp32_online
sistema/servos | ESP32 Motor | ESP32 Consola | expulsado

### 8.3. Secuencia de mensajes

La Figura 2 muestra la secuencia para dos eventos típicos: el arranque por comando del operario y la llegada de un fruto rechazado[cite: 260]. Se aprecia cómo el broker replica cada mensaje a todos los suscriptores, de modo que la consola y el motor mantienen estado

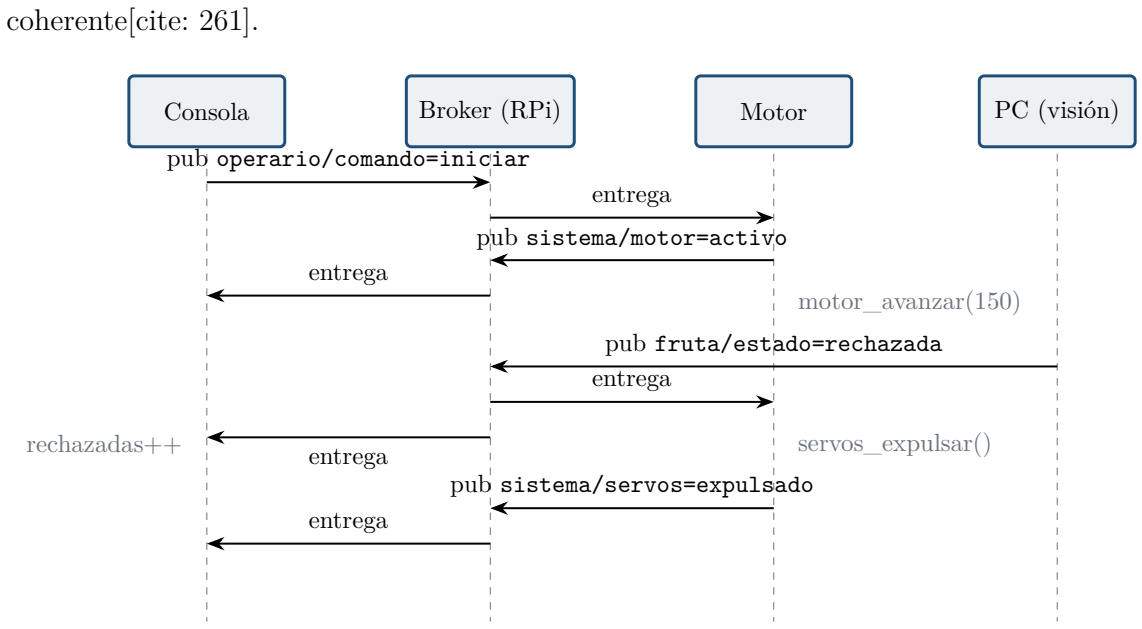
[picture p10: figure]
coherente[cite: 261].; Consola; Broker (RPi); Motor; PC (visión); pub; operario/comando=iniciar; entrega; pub sistema/motor=activo; motor_avanzar(150); pub fruta/estado=rechazada; entrega rechazadas++; servos_expulsar(); sistema/servos=expulsado

Figura 2: Diagrama de secuencia MQTT para el arranque (comando del operario) y para un fruto rechazado. El broker desacopla a los nodos y replica cada mensaje a los suscriptores[cite: 268, 269].

## 9. Diseño del firmware embebido

El firmware se desarrolla en C sobre ESP-IDF con un diseño modular[cite: 269]. El nodo Motor separa responsabilidades en config.h (pines, red, tópicos), motor, servos, mqtt_handler y wifi_manager [cite: 270]; el nodo Consola concentra OLED, botones y MQTT con tareas FreeRTOS dedicadas[cite: 271].

### 9.1. Pinout del nodo ESP32 Motor

La Tabla 6 detalla la asignación de pines del nodo Motor, derivada de config.h y del cableado del BTS7960 y los servomotores[cite: 272].

Tabla 6: Pinout del ESP32 Motor (driver BTS7960 + servomotores MG996R).

GPIO | Señal | Destino | Dir.
25 | RPWM (PWM adelante) | BTS7960 RPWM | salida
26 | LPWM (PWM atrás) | BTS7960 LPWM | salida
32 | R_EN (habilita der.) | BTS7960 R_EN | salida
33 | L_EN (habilita izq.) | BTS7960 L_EN | salida
4 | PWM Servo 1 | Servomotor 1 (50 Hz) | salida
5 | PWM Servo 2 | Servomotor 2 (50 Hz) | salida
5V/GND | Alimentación lógica | BTS7960, servos | —

### 9.2. Pinout del nodo ESP32 Consola

La Tabla 7 detalla los pines del nodo Consola (OLED I²C, botones con pull-up interno)[cite: 273, 274].

Tabla 7: Pinout del ESP32 Consola (OLED I²C, botones).

GPIO | Señal | Destino | Dir.
21 | SDA (I²C) | OLED (SSD1306 @ 0x3C) | E/S
22 | SCL (I²C) | OLED (SSD1306 @ 0x3C) | salida
14 | Botón INICIAR | a GND (pull-up int.) | entrada
27 | Botón DETENER | a GND (pull-up int.) | entrada
26 | Botón PANTALLA | a GND (pull-up int.) | entrada
25 | Botón RESET | a GND (pull-up int.) | entrada

### 9.3. Consumo eléctrico de la consola portátil

La consola está alimentada íntegramente desde una powerbank 12000 mAh (capacidad nominal 12Wh @ 5V)[cite: 274, 275]. En la Tabla 8 se desglosa el consumo de cada componente y el tiempo de autonomía estimado[cite: 275].

Tabla 8: Presupuesto de consumo eléctrico de la consola portátil.

Componente | Tipo | Voltaje | Corriente | Potencia | Duty | Notas
ESP32 (WiFi + core) | MCU | 3.3 V | 80 mA | 0.26W | 100 % | WiFi activo
OLED 128x64 | Display | 3.3 V | 20 mA | 0.07W | 100 % | Brillo normal
Botones (pull-ups) | Digital | 3.3 V | 5 mA | 0.02W | 100 % | 4 resistencias 10 k
Total ESP32 | | | 105 mA | 0.35W
DC-DC Regulador | Boost 5V3.3V | 5 V | 63 mA | 0.32W | 91 % | Eficiencia típica
Consumo Total | | 5V | 168 mA | 0.84W

Autonomía con powerbank 12000 mAh @ 5V nominal: Tiempo = 12000 mAh / 168 mA ≈ 71 horas (continuo) Operación típica (∼8 horas/turno): Múltiples turnos sin recarga

En la práctica, el consumo puede variar: modo profundo (light sleep) reduce a ∼10 mA; actividad de botones es esporádica[cite: 277, 278]. La powerbank ofrece autonomía de 2–3 días de operación típica (8 horas/día)[cite: 278].

### 9.4. Concurrencia con FreeRTOS: disparo no bloqueante de servomotores

El patrón embebido más relevante del proyecto resuelve RF-04[cite: 279]. Cuando llega fruta/estado=rechazada, el callback de MQTT no gira los servomotores directamente (eso lo bloquearía 350 ms), sino que notifica a una tarea dedicada mediante xTaskNotifyGive [cite: 280]; la tarea mueve los servos, espera con vTaskDelay y publica la confirmación, todo sin congelar el hilo de red[cite: 281]. El Código 1 muestra esta tarea[cite: 282].

1 | static void tarea_servos_expulsion ( void * arg ) {
2 | while (1) {
3 | // Bloquea aqu í hasta recibir x T a s k N o t i f y G i v e () desde el callback MQTT
4 | ulTaskNotifyTake ( pdTRUE , portMAX_DELAY );
5 | ESP_LOGI ( TAG , " >>> Disparando servomotores a 180 grados ");
6 | servo_set_angle (1 , 180) ; | // Servo 1 abre (180 °)
7 | servo_set_angle (2 , 180) ; | // Servo 2 abre (180 °)

8
9 | vTaskDelay ( pdMS_TO_TICKS (300) ); // Mantener 300 ms

10
11 | servo_set_angle (1 , 90) ; | // Servo 1 retorna a neutral (90 °)
12 | servo_set_angle (2 , 90) ; | // Servo 2 retorna a neutral (90 °)

13
14 | vTaskDelay ( pdMS_TO_TICKS (50) ) ; | // Estabilizaci ón

15
16 | ESP_LOGI ( TAG , " >>> Servomotores retornados a neutral ");
17 | if ( cliente_mqtt )
18 | esp_mqtt_client_publish ( cliente_mqtt , TOPIC_SERVOS , " expulsado ", 0, 1, 0) ;
19 | }
20 | }
Listing 1: Tarea FreeRTOS de los servomotores: espera una notificación, gira a 180ř, retorna a neutral y confirma por MQTT, sin bloquear el hilo del broker.

El callback de MQTT del nodo Motor interpreta los tópicos suscritos y solo dispara cuando el sistema está activo, como muestra el Código 2[cite: 290].

if ( strcmp ( topic , TOPIC_COMANDO ) == 0) {
if ( strcmp ( data , " iniciar ") == 0) {
sistema_activo = true ;
motor_avanzar ( MOTOR_VEL_NORMAL );
esp_mqtt_client_publish ( client , TOPIC_MOTOR , " activo ", 0, 1, 0) ; } else if ( strcmp ( data , " detener ") == 0) {
sistema_activo = false ;
motor_detener () ;
esp_mqtt_client_publish ( client , TOPIC_MOTOR , " detenido ", 0, 1, 0) ;
}
}
else if ( strcmp ( topic , TOPIC_FRUTA ) == 0 && sistema_activo ) { if ( strcmp ( data , " rechazada ") == 0)
xTaskNotifyGive ( tarea_servos_handle ); // NOTIFICA a la tarea , no bloquea
}
Listing 2: Manejo de eventos MQTT en el nodo Motor (caso de datos recibidos con servomotores).

### 9.5. Máquinas de estados finitos (FSM) actualizadas

El comportamiento de cada nodo se modela como una máquina de estados finitos[cite: 294]. La Figura 3 presenta la FSM del nodo Motor actualizada con servomotores: tras el arranque conecta WiFi y MQTT, y alterna entre DETENIDO y ACTIVO según los comandos; en ACTIVO, un veredicto rechazada dispara los servomotores[cite: 295, 296].

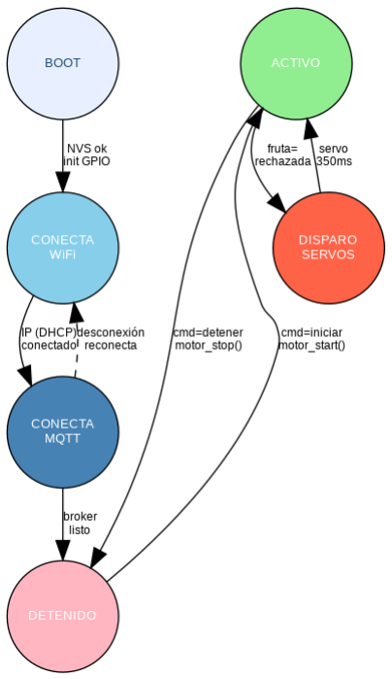
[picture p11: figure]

Figura 3: FSM del nodo ESP32 Motor actualizada con servomotores MG996R. El estado DISPARO SERVOS se ejecuta en una tarea FreeRTOS separada (no bloqueante, duración total 350 ms)[cite: 296, 297].

La Figura 4 muestra la FSM de navegación de pantallas de la consola: el botón PANTA-LLA rota entre CONTADORES, DIAGNÓSTICO y ALERTA [cite: 297]; tres rechazos consecutivos fuerzan el salto a ALERTA y lo muestran en pantalla OLED [cite: 298]; el botón RESET limpia contadores y alerta[cite: 299].

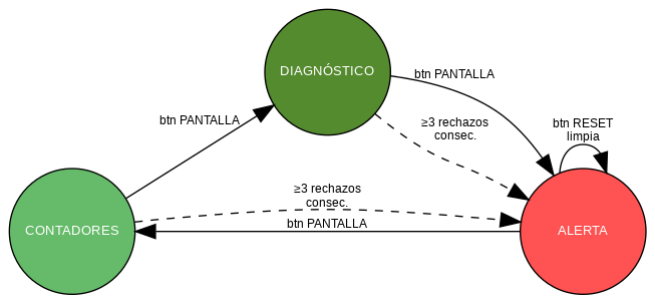
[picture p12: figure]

Figura 4: FSM de pantallas de la consola OLED. La transición forzada a ALERTA se dispara con tres rechazos consecutivos[cite: 299, 300].

## 10. Caracterización y gráficas de respuesta

### 10.1. Señal PWM del motor

El periférico LEDC genera la señal PWM a 10 kHz sobre RPWM (GPIO25)[cite: 300]. Con MOTOR_VEL_NORMAL=150 sobre 255, el ciclo de trabajo es del 58.8 %, como se observa en la Figura 5[cite: 301]. La Figura 6 muestra la relación lineal entre el valor de duty (8 bits) y la tensión media aplicada al motor, y el punto de operación elegido[cite: 302].


Figura 5: Señal PWM a 10 kHz en GPIO25 con ciclo de trabajo de 150/255 (58.8 %). Período de 100 ţs[cite: 303, 304].


Figura 6: Cuantización del PWM: el duty de 8 bits se mapea linealmente a la tensión media en el motor. En rojo, el punto de arranque (duty=150)[cite: 304, 305].

### 10.2. Cronograma del disparo de servomotores

La Figura 7 muestra la temporización del disparo no bloqueante: el evento MQTT rechazada
provoca el giro de los servomotores (GPIO4, GPIO5) desde 90ř a 180ř durante SERVO_MS=300 ms
; los servos actúan mecánicamente y, al retornar a neutral, el nodo publica sistema/servos=expulsado[cite: 308].

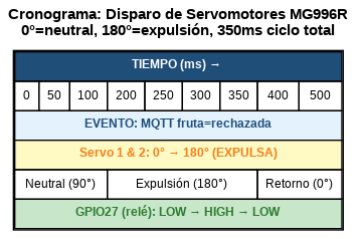
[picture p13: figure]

Figura 7: Cronograma del disparo de servomotores gestionado por la tarea FreeRTOS dedicada. Incluye rampas de giro y estabilización[cite: 309, 310].

### 10.3. Presupuesto de latencia extremo a extremo

La Figura 8 descompone el tiempo total desde la captura hasta la expulsión[cite: 310]. La etapa dominante es la inferencia de visión en la PC [cite: 311]; las etapas de red y reacción embebida suman pocas decenas de milisegundos, de modo que el total se mantiene holgadamente por debajo de los 2 s (RNF-01) y determina la velocidad máxima admisible de la banda[cite: 312].


Figura 8: Presupuesto de latencia extremo a extremo (valores típicos/de especificación). La inferencia domina; la cadena MQTT + reacción embebida es despreciable frente a ella[cite: 313, 314].

## 11. Aplicación real: producción de tomate en Tarija

El fin último de la cinta es servir como herramienta de control de calidad poscosecha accesible a pequeños productores de tomate[cite: 314]. Tarija reúne condiciones idóneas: pese a ser el departamento más pequeño de Bolivia, dispone de unas 189.268 hectáreas con vocación productiva agrícola El Diario, 2026, y el tomate es uno de los cultivos relevantes de sus valles El País (Tarija), 2023[cite: 315].

Comunidad propuesta: Chocloca (municipio de Uriondo, Valle Central). Se propone como caso de aplicación la comunidad de Chocloca, uno de los nueve distritos del municipio de Uriondo (provincia José María Avilés), a unos 25 km al sur de la ciudad de Tarija, en el Valle Central[cite: 316]. El municipio agrupa 53 comunidades campesinas, de las cuales más del 90 % se dedica a la agricultura, con el tomate entre sus principales cultivos junto a la vid, la papa y el morrón El País (Tarija), 2023[cite: 317]. Chocloca pertenece a la cuenca del río Camacho, de clima templado (temperatura media diaria máxima cercana a 26 řC y precipitación media anual en torno a 740 mm) Erazo Campos, 2003; Wikipedia, 2024, lo que favorece varias campañas hortícolas al año[cite: 318].

Por qué es un caso idóneo. Varios factores hacen pertinente el prototipo en esta comunidad:

Clasificación manual y pérdidas. La selección del tomate se hace a mano [cite: 319]; un fruto deteriorado no detectado contamina el resto del lote, generando pérdidas[cite: 320].

Vulnerabilidad de la oferta. La producción de tomate en Tarija llegó a caer hasta un 60 % por sequías y heladas [cite: 321]; en un contexto de oferta ajustada, reducir el descarte tiene impacto económico directo[cite: 322].

Contexto rural sin Internet. La arquitectura del proyecto opera sobre una red WiFi local autónoma (RPi como Access Point) y una consola a batería [cite: 323]; no requiere conectividad externa (RNF-05)[cite: 324].

## Referencias Bibliográficas

Banks, A., & Gupta, R. (2014). MQTT Version 3.1.1 (OASIS Standard). OASIS. Consultado el 6 de junio de 2026, desde https://docs.oasis-open.org/mqtt/mqtt/v3.1.1/os/mqtt-v3.1.1-os.html
Barry, R. (2016). Mastering the FreeRTOS Real Time Kernel: A Hands-On Tutorial Guide. Real Time Engineers Ltd.
El Diario. (2026). Tarija tiene más de 1,6 millones de hectáreas con alto potencial productivo agropecuario. Consultado el 7 de junio de 2026, desde https://www.eldiario.net/portal/2026/04/16/tarija- tiene-mas-de-16-millones-de-hectareas-con-altopotencial-productivo-agropecuario/
El País (Tarija). (2023). Avilés y la variedad de su producción agrícola. Consultado el 7 de junio de 2026, desde https://elpais.bo/tarija/20230415_aviles-y-la-variedad-desu-produccion-agricola.html
Erazo Campos, O. (2003). Uso de la totora en la producción agrícola de la cuenca del río Camacho, Tarija, Bolivia. LEISA Revista de Agroecología, 19 (3).
Espressif Systems. (2023). ESP32 Technical Reference Manual (Version 5.1). Espressif Systems. Consultado el 6 de junio de 2026, desde https://www.espressif.com/sites/default/files/documentation/esp32_technical_reference_manual_en.pdf Espressif Systems. (2024). ESP-IDF Programming Guide (v5.x): Wi-Fi, MQTT, LEDC y FreeRTOS. Consultado el 6 de junio de 2026, desde https://docs.espressif.com/projects/esp-idf/en/stable/esp32/
Gonzalez, R. C., & Woods, R. E. (2018). Digital Image Processing (4th). Pearson. IEEE. (2021). IEEE Standard for Information Technology – Telecommunications and Information Exchange between Systems – Local and Metropolitan Area Networks (IEEE 802.11-2020) (Standard). Institute of Electrical y Electronics Engineers. Infineon Technologies. (2004). BTS7960 High Current PN Half Bridge – Data Sheet. Infineon Technologies AG. Consultado el 6 de junio de 2026, desde https://www.infineon.com/dgdl/bts7960.pdf
Light, R. A. (2017). Mosquitto: server and client implementation of the MQTT protocol. The Journal of Open Source Software, 2 (13), 265. https://doi.org/10.21105/joss. 00265
OpenCV Development Team. (2024). OpenCV Documentation. Consultado el 1 de abril de 2026, desde https://docs.opencv.org
Universidad Católica Boliviana "San Pablo". (2026). Guía de proyectos del Departamento de Ciencias de la Tecnología e Innovación (DCT). Consultado el 30 de marzo de 2026, desde https://www.ucb.edu.bo
Wikipedia. (2024). Uriondo (datos climáticos de Chocloca, 1975–2010). Consultado el 7 de junio de 2026, desde https://en.wikipedia.org/wiki/Uriondo

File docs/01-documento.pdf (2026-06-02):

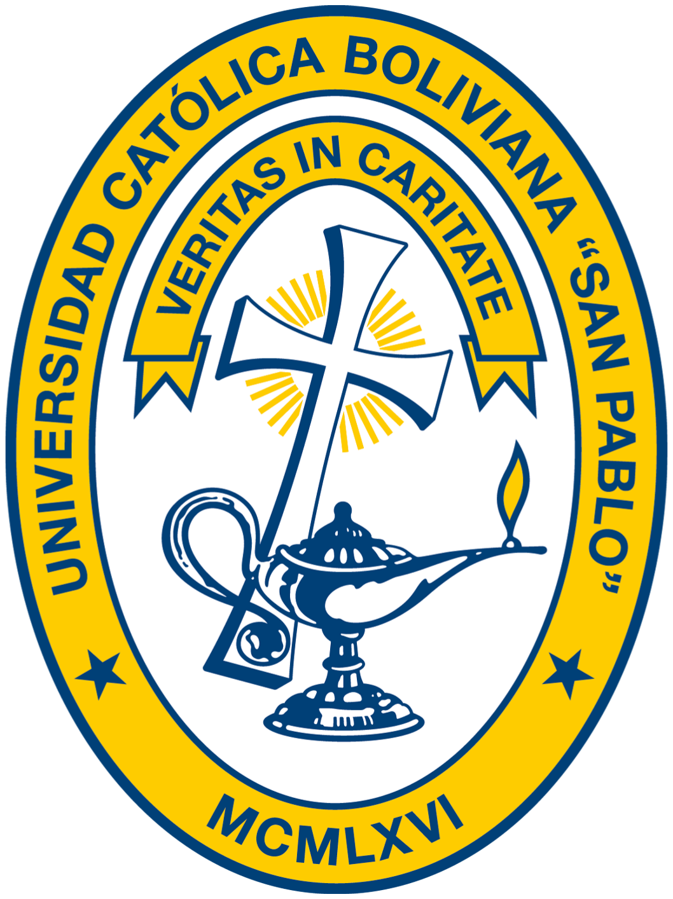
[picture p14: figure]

Universidad Catolica Boliviana ”San Pablo” ´

Departamento de Ciencias de la Tecnología e Innovacion´

Ingeniería Mecatronica ´

# Sistema Automático de Clasificación de Frutas mediante Visión Artificial y ESP32


### Materia: Sistemas Embebidos II

Estudiante(s): Susann Baldiviezo C. Alejandro Bejarano R.
Florencia Frigerio A.
Benjamín Soruco G.
Docente: Msc. Ing. Alan Cornejo Q.

### Semestre: 1/2026

### Bolivia, 4 de mayo de 2026

2

## Índice

1. Descripción técnica-conceptual del proyecto a realizar | 1
2. Propósito del proyecto | 2
3. Alcance del proyecto | 2
4. Supuestos del proyecto | 3
5. Requerimientos | 4
6. Entregables principales del proyecto | 6

### 7. Consola portátil para el operario (Unidad de Monitoreo y Control Móvil) 7

Referencias Bibliográficas | 10

## Índice de figuras

## Índice de tablas

## 1. Descripción técnica-conceptual del proyecto a realizar

El presente proyecto consiste en el diseño e implementación de un sistema automático de clasificación de frutas en general mediante técnicas de visión artificial y sistemas embebidos. El sistema integra dos cámaras posicionadas estratégicamente en la parte superior de una banda transportadora, desde ángulos distintos, con el objetivo de capturar la mayor superficie visible de cada fruta y detectar con mayor precisión zonas de deterioro o descomposición.

El procesamiento de imágenes se realiza en una computadora personal (PC o laptop) mediante el uso de la biblioteca OpenCV OpenCV Development Team, 2024, aplicando algoritmos de análisis de color y textura para identificar frutas en estado de descomposición. Una vez que el sistema de visión artificial emite un veredicto, la señal de control es transmitida a una placa ESP32 Espressif Systems, 2023, que actúa como controlador embebido encargado de gestionar los actuadores físicos: la banda transportadora y el cilindro neumático de expulsión.

El cilindro neumático, accionado mediante una válvula solenoide controlada por la ESP32, se encarga de desviar físicamente las frutas clasificadas como deterioradas fuera de la línea principal, separándolas de aquellas en buen estado. De este modo, el sistema ofrece una solución automatizada, eficiente y de bajo costo para el control de calidad en procesos de selección frutícola.

Como complemento al sistema central, se incorpora una consola portátil basada en una segunda ESP32 que permite al operario monitorear el estado del proceso en tiempo real desde cualquier punto de la planta, sin necesidad de permanecer frente a la PC principal. Además, desde esta consola el operario podrá iniciar y detener el proceso completo de clasificación.

En la Tabla 1 se presenta la arquitectura general del sistema, mostrando las entradas, procesamiento, control embebido y salidas del mismo.

Tabla 1: Arquitectura general del sistema.
Entradas | Procesamiento | Control Embebi-do | Salidas
2 cámaras superiores USB/IP | PC con OpenCV (Python) | ESP32 principal | Fruta clasificada
Parámetros: calidad y espe-cie | Análisis de color y textura | Controla banda y actuadores | Expulsión por cilindro
Sensor opcional de presencia | Decisión: buen/mal estado | Comunicación se-rial/WiFi | Registro de re-sultados

## 2. Propósito del proyecto

El propósito principal del proyecto es automatizar el proceso de clasificación de frutas en general mediante la detección de deterioro o descomposición a través de visión artificial Gonzalez y Woods, 2018. Con ello se busca:

Reducir la intervención humana en tareas repetitivas y de alto margen de error visual.

Mejorar la eficiencia y velocidad del proceso de selección en líneas de producción agroindustrial.

Minimizar las pérdidas económicas generadas por la comercialización de fruta en mal estado.

Aplicar conceptos teórico-prácticos de sistemas embebidos y visión artificial en un prototipo funcional real.

Demostrar la viabilidad técnica de integrar una ESP32 con un sistema de visión por computadora de bajo costo, incluyendo una consola portátil de monitoreo y control para el operario de planta.

Desde la perspectiva académica, el proyecto permite integrar y aplicar los conocimientos de la materia de Sistemas Embebidos II en un contexto de ingeniería real, abordando la comunicación entre hardware y software, el control de actuadores y la adquisición de señales de cámara.

## 3. Alcance del proyecto

El proyecto abarca el diseño, construcción y validación de un prototipo funcional de clasificación de frutas en general. A continuación se detallan los límites del alcance.

### 3.1. Lo que el sistema SÍ contempla

Detección visual de fruta en estado de descomposición mediante dos cámaras superiores y OpenCV.

Control de la banda transportadora a través de la ESP32.

Activación del cilindro neumático para la expulsión física de fruta deteriorada.

Comunicación entre la PC (sistema de visión) y la ESP32 (sistema embebido).

Operación bajo condiciones de iluminación controlada y ambiente de laboratorio.

Clasificación de fruta en dos categorías: buen estado y mal estado.

Consola portátil basada en una segunda ESP32 para monitoreo inalámbrico en tiempo real y control del proceso por parte del operario de planta.

### 3.2. Lo que el sistema NO contempla

El presente proyecto no incluye:

Clasificación por tamaño, peso o madurez de la fruta (solo estado de descomposición).

Operación en entornos industriales de alta velocidad o con múltiples tipos de fruta simultáneamente.

Implementación de interfaz gráfica avanzada o panel de control remoto vía red (más allá de la consola portátil del operario).

Integración con sistemas ERP o bases de datos de trazabilidad industrial.

## 4. Supuestos del proyecto

Para el desarrollo del presente proyecto se supone que:

Iluminación controlada: El prototipo operará bajo condiciones de iluminación artificial controlada y constante, eliminando variaciones de luz ambiental que puedan afectar el análisis de color y textura de las imágenes capturadas.

Fruta sobre banda transportadora: Las frutas serán colocadas manualmente sobre la banda en posición individual y con separación suficiente para ser analizadas de manera independiente.

Velocidad de banda constante: La velocidad de desplazamiento será fija y calibrada previamente para que el sistema de visión tenga tiempo suficiente de capturar y procesar cada fruta.

Comunicación confiable PC-ESP32: Se asume disponibilidad de comunicación serial (USB) o inalámbrica estable entre la computadora de procesamiento y la placa ESP32 principal.

Red WiFi local disponible: Existe disponibilidad de red WiFi local (o Access Point generado por la ESP32 principal) para la comunicación con la consola portátil del operario.

Componentes disponibles: El equipo cuenta con los componentes físicos necesarios para la construcción del prototipo (incluyendo la segunda ESP32 y pantalla TFT para la consola portátil).

Uso en ambiente de laboratorio: El prototipo es diseñado para operar en condiciones de laboratorio o taller académico, no en ambientes industriales con polvo, humedad extrema o temperaturas fuera de rango.

## 5. Requerimientos

### 5.1. Requerimientos de Hardware

En la Tabla 2 se listan los componentes de hardware del sistema, incluyendo los correspondientes a la consola portátil del operario (H-10 a H-14).

Tabla 2: Requerimientos de hardware del sistema.

ID | Componente | Descripción | Cant.
H-01 | ESP32 (o similar) | Microcontrolador para control de actuadores y comunicación con la PC | 1
H-02 | Cámaras USB/IP (o similar) | 2 cámaras superiores en ángulos distintos para captura de imáge-nes | 2
H-03 | Cilindro neumático (o similar) | Actuador para expulsión física de fruta deteriorada | 1
H-04 | Válvula solenoide (o similar) | Controla el paso de aire al cilindro neumático (GPIO) | 1
H-05 | Banda transportado-ra (o similar) | Motor + cinta para desplaza-miento de la fruta | 1
H-06 | Compresor de aire (o similar) | Suministra aire comprimido al ci-lindro neumático | 1
H-07 | PC / Laptop (o simi-lar) | Equipo de cómputo para procesa-miento de imágenes con OpenCV | 1
H-08 | Fuente de alimenta-ción (o similar) | Suministro eléctrico para PC, cámaras y motor | 1
H-09 | Iluminación artificial (o similar) | Fuente de luz controlada sobre la zona de inspección | 1
H-10 | ESP32 consola (o si-milar) | Segunda placa dedicada a la uni-dad portátil de monitoreo y con-trol | 1
H-11 | Pantalla TFT SPI ILI9341 (o similar) | Display a color 2.4”–3.5” para vi-sualización de datos en tiempo real | 1
H-12 | Batería LiPo 3.7 V + TP4056 (o similar) | Sistema de alimentación autóno-ma recargable para la consola portátil | 1
H-13 | Botones táctiles x4 (o similar) | Interfaz física para navegación y control por parte del operario | 4
H-14 | Buzzer + LED RGB (o similar) | Alertas sonoras y visuales para notificaciones del sistema | 1 c/u

### 5.2. Requerimientos de Software

En la Tabla 3 se detallan los componentes de software requeridos.

Tabla 3: Requerimientos de software del sistema.
ID | Software | Descripción | Versión
S-01 | Python 3.x | Lenguaje de programación para el módulo de visión artificial | 3.10+
S-02 | OpenCV (o simi-lar) | Biblioteca de visión por compu-tadora para análisis de co-lor/textura | 4.x
S-03 | NumPy (o similar) | Manejo de arrays y operaciones matemáticas sobre imágenes | Latest
S-04 | Arduino IDE / ESP-IDF (o simi-lar) | Entorno de desarrollo para pro-gramar la ESP32 | Latest
S-05 | PySerial (o similar) | Comunicación serial entre Python y la ESP32 | Latest
S-06 | TFT eSPI (o simi-lar) | Driver para control eficiente de pantallas SPI en ESP32 | Latest
S-07 | PubSubClient (o si-milar) | Cliente MQTT ligero para ESP32; suscripción y publicación de mensajes | Latest
S-08 | Mosquitto MQTT Broker (o similar) | Broker de mensajería liviano ins-talado en la PC central | 2.x

### 5.3. Requerimientos Funcionales

1. Requerimientos del sistema principal de clasificación:

RF-01 El sistema debe capturar imágenes de cada fruta desde dos cámaras superiores en tiempo real.

RF-02 El algoritmo debe analizar color y textura para detectar zonas de descomposición en la superficie de la fruta.

RF-03 El sistema debe clasificar cada fruta en “buen estado” o “mal estado” de forma automática.

RF-04 La ESP32 debe recibir la señal de clasificación y activar o no el cilindro neumático en consecuencia.

RF-05 La banda transportadora debe detenerse o ajustar su velocidad cuando una fruta esté siendo analizada.

2. Requerimientos de la consola portátil del operario:

RF-06 La consola debe recibir y mostrar en pantalla los datos de clasificación con una latencia máxima de 1 segundo desde que la PC emite el veredicto.

RF-07 El operario debe poder iniciar, pausar y reanudar tanto la banda como el proceso completo de clasificación desde la consola portátil mediante botones dedicados.

RF-08 La consola debe emitir una alerta sonora (buzzer) cuando se detecte un volumen elevado de fruta rechazada de forma consecutiva.

RF-09 La consola debe indicar visualmente (LED o mensaje en pantalla) cuando se pierda la comunicación WiFi con el sistema central.

RF-10 La consola debe funcionar de forma autónoma (sin cable) gracias a la batería LiPo integrada.

RF-11 El operario debe poder iniciar y detener el proceso completo (banda + sistema de visión) directamente desde la consola portátil, sin necesidad de acceder a la PC principal.

### 5.4. Requerimientos No Funcionales

RNF-01 El tiempo de procesamiento por fruta no debe superar los 2 segundos.

RNF-02 El sistema debe operar de manera continua durante al menos 30 minutos sin fallos.

RNF-03 El código debe estar estructurado de forma modular y documentado.

RNF-04 El prototipo debe ser reproducible con componentes de bajo costo disponibles en el mercado local.

## 6. Entregables principales del proyecto

El entregable principal del proyecto es el prototipo físico funcional del sistema de clasificación de frutas. En la Tabla 4 se describen sus componentes.

El prototipo deberá demostrar en funcionamiento la cadena completa: captura de imagen → procesamiento con OpenCV → decisión → señal a ESP32 → acción del cilindro neumático, con frutas reales en condiciones de buen estado y mal estado. Adicionalmente, la consola portátil deberá mostrar en tiempo real los resultados recibidos vía WiFi/MQTT y permitir al operario controlar el proceso desde la misma.

Tabla 4: Entregables del proyecto.
Entregable | Descripción | Estado
Prototipo físico | Banda transportadora con cámaras, cilindro neumático y ESP32 principal integrados y funcionando | Principal
Módulo de visión | Script Python con OpenCV que detecta fruta deteriorada en tiempo real desde 2 cámaras | Incluido
Firmware ESP32 | Código embebido para control de banda, válvula y comunicación con PC (vía MQTT y serial) | Incluido
Consola portátil | Hardware (ESP32 + TFT + batería + boto-nes) y firmware de la unidad de monitoreo y control del operario | Incluido
Demostración en vivo | Presentación del sistema funcionando con frutas reales ante el docente | Incluido

## 7. Consola portátil para el operario (Unidad de Monitoreo y Control Móvil)

Como complemento al sistema central de clasificación, se incorpora una consola portátil que permite al operario de planta monitorear en tiempo real el estado del proceso e iniciar o detener el proceso completo sin necesidad de permanecer frente a la PC principal. Esta unidad móvil está basada en una segunda placa ESP32 y actúa como terminal de visualización y control inalámbrico, recibiendo y enviando datos al sistema central mediante comunicación WiFi (protocolo MQTT).
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

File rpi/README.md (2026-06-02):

# Raspberry Pi — Configuración del servidor

## Rol en el sistema

La RPi actúa como el **núcleo de comunicación** del proyecto:

- **Broker MQTT (Mosquitto):** distribuye mensajes entre la PC, el ESP32 motor y el ESP32 consola
- **Access Point WiFi:** crea la red `CintaTransportadora` para que el sistema sea completamente portátil
- **IP fija:** `192.168.4.1` (AP) / `192.168.1.100` (Ethernet)

---

## Archivos de configuración

| Archivo | Descripción |
|---|---|
| `mosquitto.conf` | Configuración del broker MQTT |
| `setup_ap.sh` | Script para crear el Access Point con nmcli |
| `setup_mosquitto.sh` | Script de instalación y configuración de Mosquitto |
| `systemd/cinta-mqtt.service` | Servicio systemd para Mosquitto (arranque automático) |

---

## Acceso SSH

```bash
# Por Ethernet (configuración y mantenimiento)
ssh raspi@192.168.1.100

# Por WiFi AP (uso normal en demo)
ssh raspi@192.168.4.1
```

Si dice "REMOTE HOST IDENTIFICATION HAS CHANGED":
```bash
ssh-keygen -R 192.168.4.1
ssh raspi@192.168.4.1
```

---

## Comandos de uso frecuente

```bash
# Estado del broker MQTT
sudo systemctl status mosquitto
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

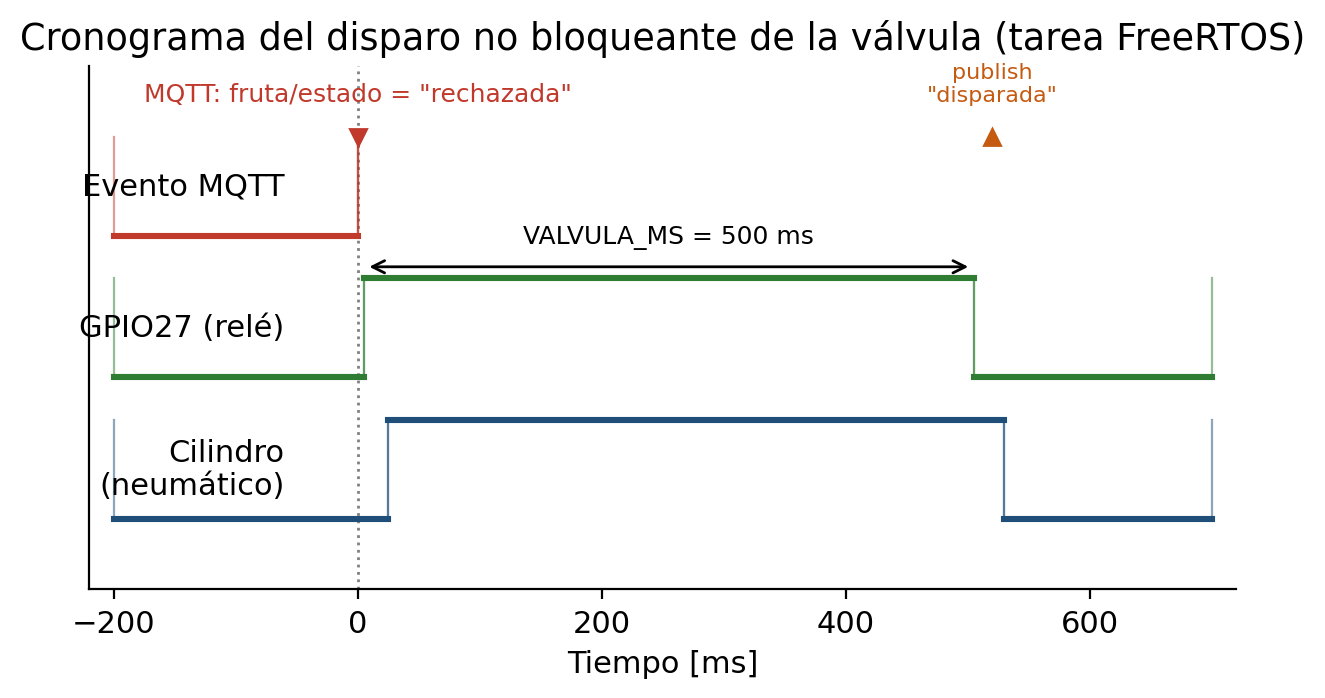
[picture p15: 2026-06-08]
docs/informe_EMBII/entrega/Figuras/cronograma_valvula.png

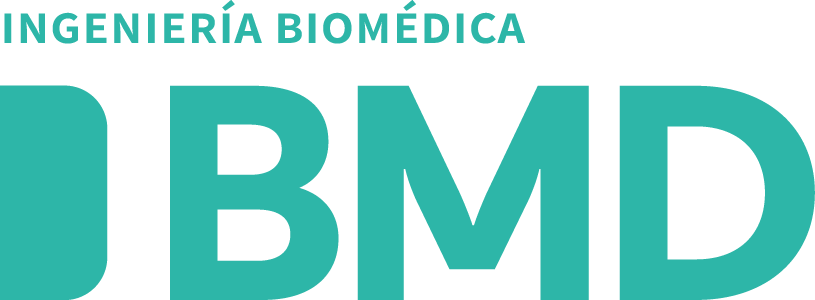
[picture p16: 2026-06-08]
docs/informe_EMBII/entrega/Figuras/bmd.png

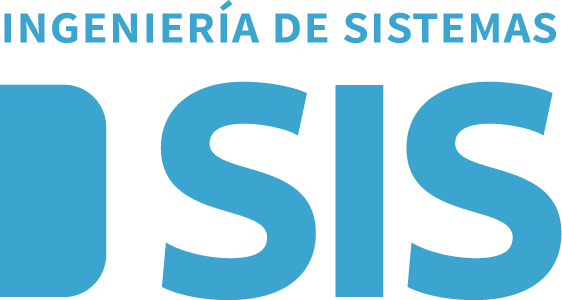
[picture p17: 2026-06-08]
docs/informe_EMBII/entrega/Figuras/sis.png

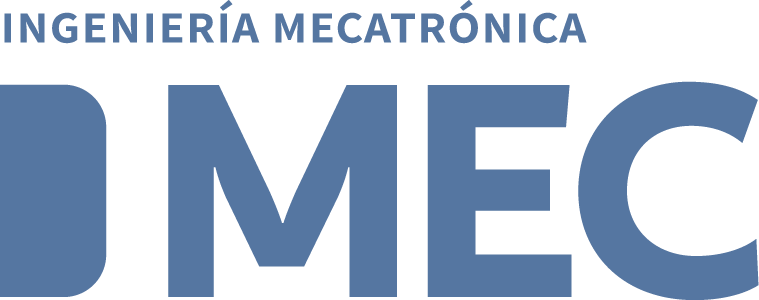
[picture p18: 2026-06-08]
docs/informe_EMBII/entrega/Figuras/mec.png

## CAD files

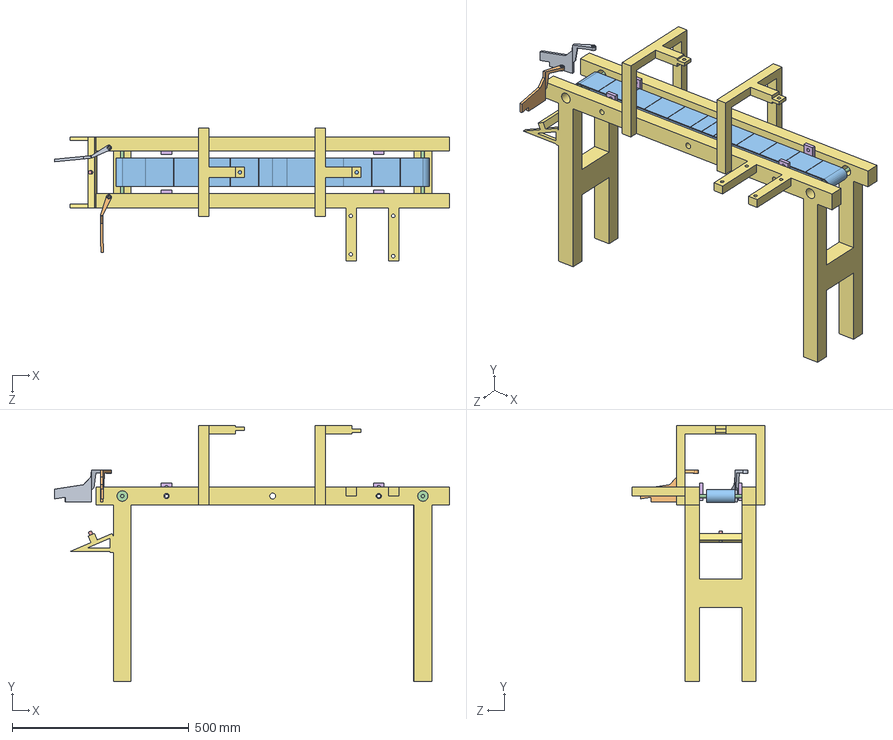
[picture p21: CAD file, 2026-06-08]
chassis/chassis_designes/Ensamblaje1.SLDASM
1116.8 x 725.0 x 375.0 mm
Pieza1
RODILLO x 2
banda
acople izquierdo
acople derecho

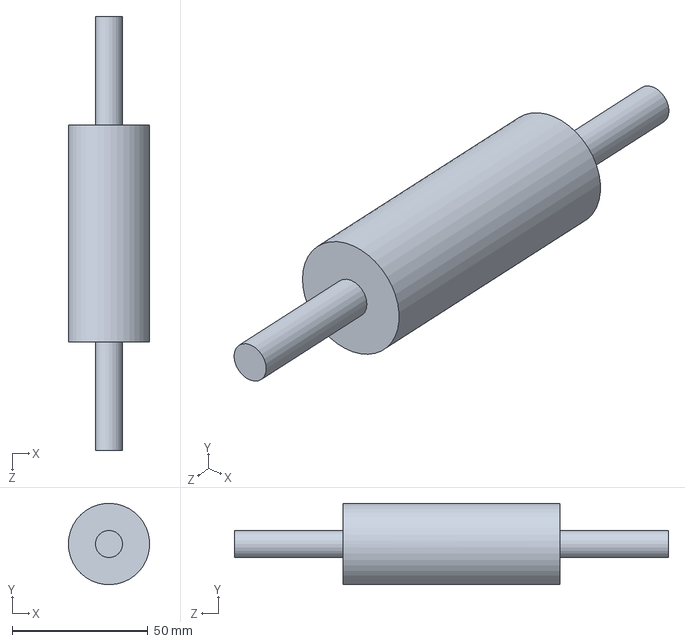
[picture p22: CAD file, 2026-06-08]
chassis/chassis_designes/RODILLO.SLDPRT
30.0 x 30.0 x 160.0 mm

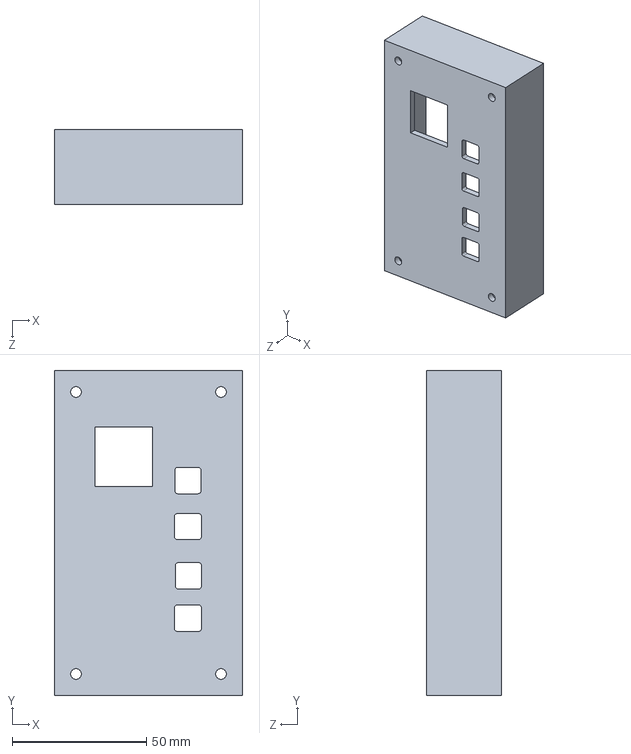
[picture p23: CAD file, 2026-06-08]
hardware/carcasa/02_consola/MANDO/TAPA.SLDPRT
70.0 x 121.0 x 28.0 mm

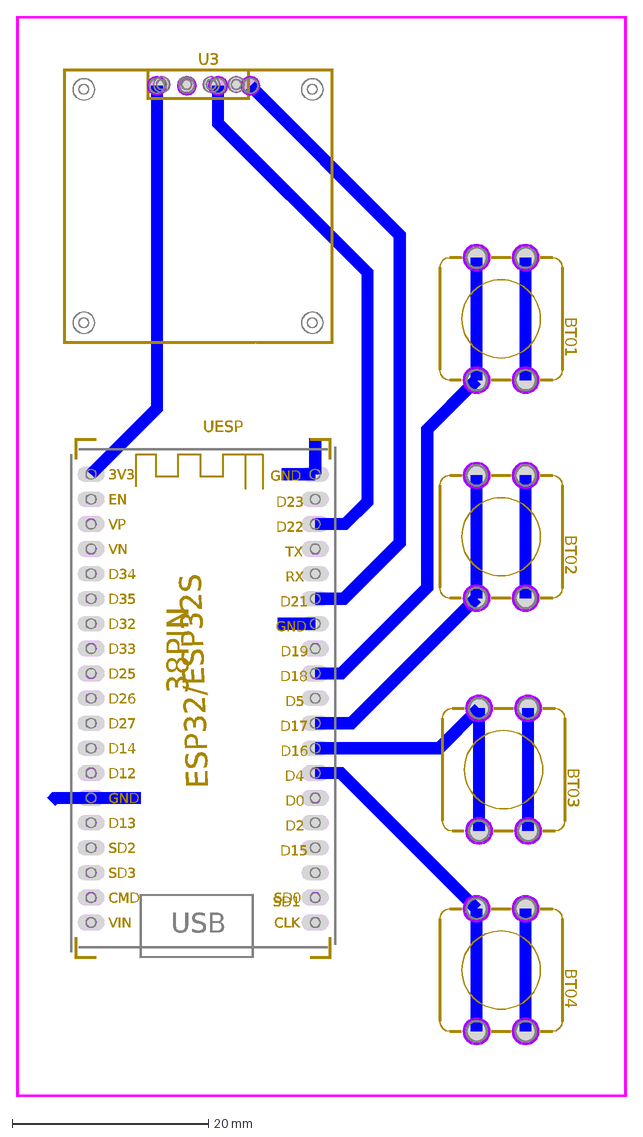
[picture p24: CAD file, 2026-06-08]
hardware/carcasa/02_consola/PCB_02_proy_mando_cinta-oledSINresistencias_2026-06-05 (1).dxf
UESP
USB
TX
D22
D23
RX
D21
GND
D19
D18
D5
D17
D16
D4
D0
D2
D15
D12
D14
D27
D26
D25
D33
D32
D35
D34
VN
VP
EN
SD3
CMD
VIN
3V3
SD1
SD0
CLK
ESP32/ESP32S
38PIN
D13
SD2
BT04
BT03
BT02
BT01
U3

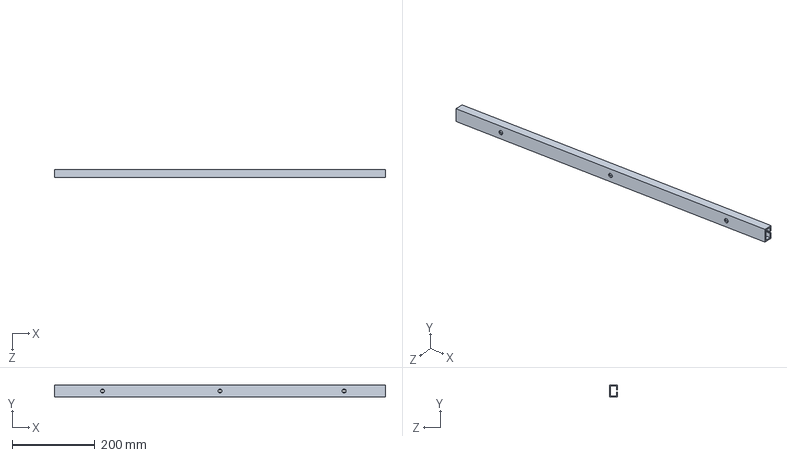
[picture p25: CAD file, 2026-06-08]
chassis/chassis_designes/1.SLDPRT
800.0 x 30.0 x 20.0 mm

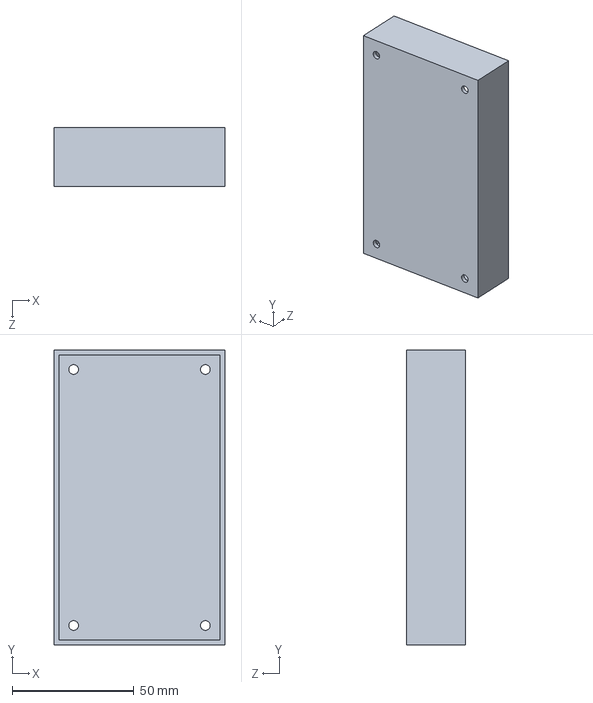
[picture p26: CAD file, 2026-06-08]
hardware/carcasa/02_consola/MANDO/BASE.SLDPRT
70.0 x 121.0 x 24.0 mm

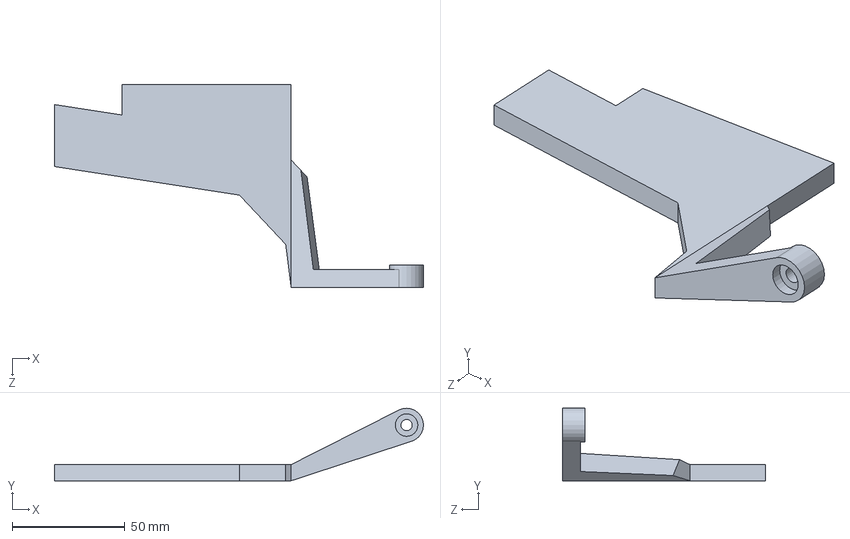
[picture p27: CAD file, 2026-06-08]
chassis/chassis_designes/acople derecho.SLDPRT
163.8 x 32.2 x 90.0 mm

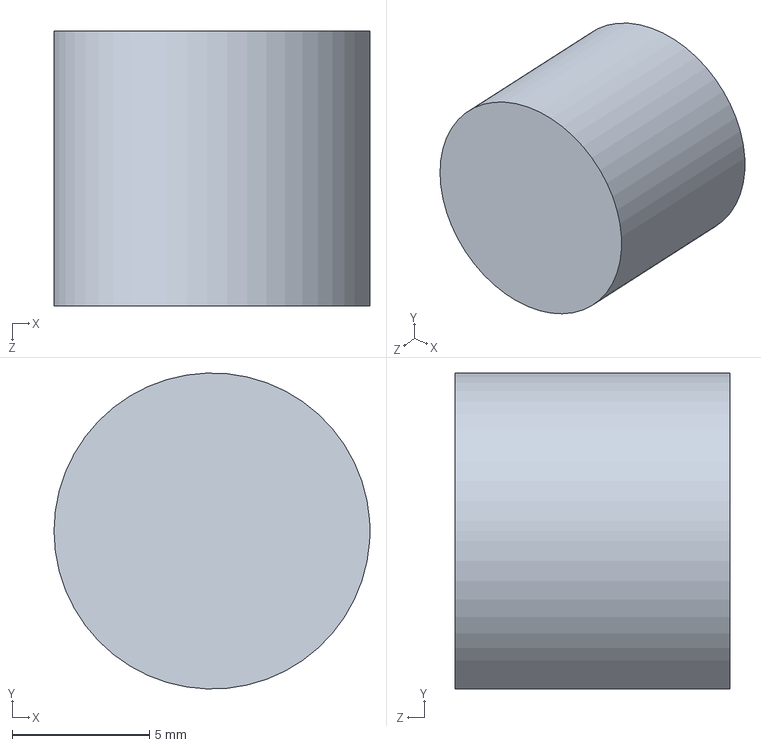
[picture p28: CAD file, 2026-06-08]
hardware/carcasa/02_consola/MANDO/BOTONCITO.SLDPRT
11.5 x 11.5 x 10.0 mm

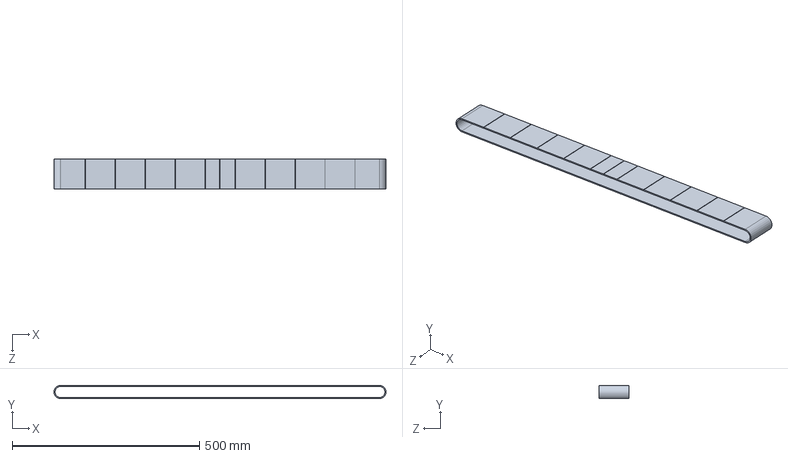
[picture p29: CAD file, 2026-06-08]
chassis/chassis_designes/banda.SLDPRT
886.0 x 36.0 x 80.0 mm

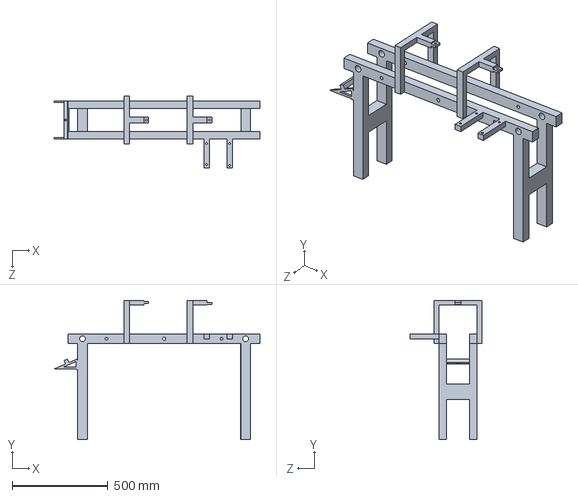
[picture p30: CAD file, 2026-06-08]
chassis/chassis_designes/Pieza1.SLDPRT
1073.6 x 725.0 x 375.0 mm

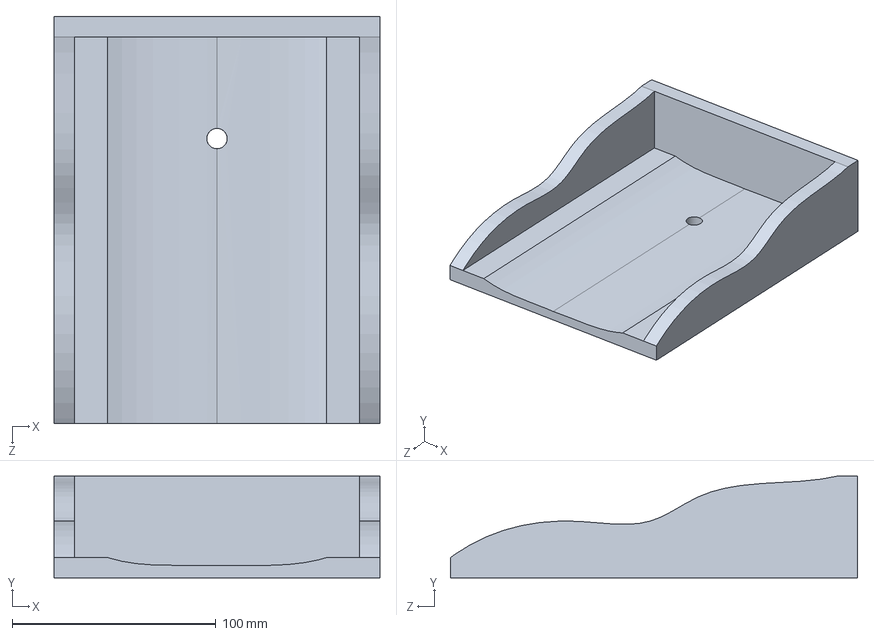
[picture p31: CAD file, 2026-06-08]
chassis/chassis_designes/3.SLDPRT
160.0 x 50.0 x 200.0 mm

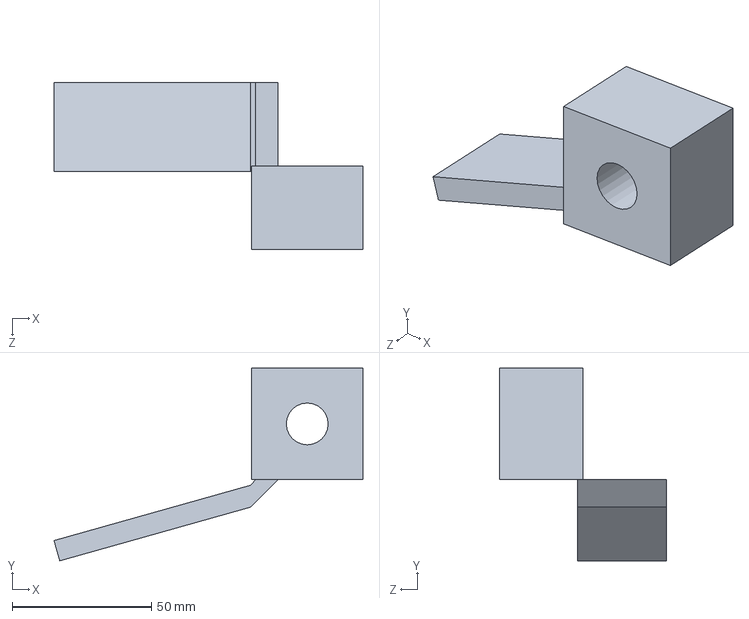
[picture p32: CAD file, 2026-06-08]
chassis/chassis_designes/PALA1.SLDPRT
110.8 x 69.1 x 60.0 mm

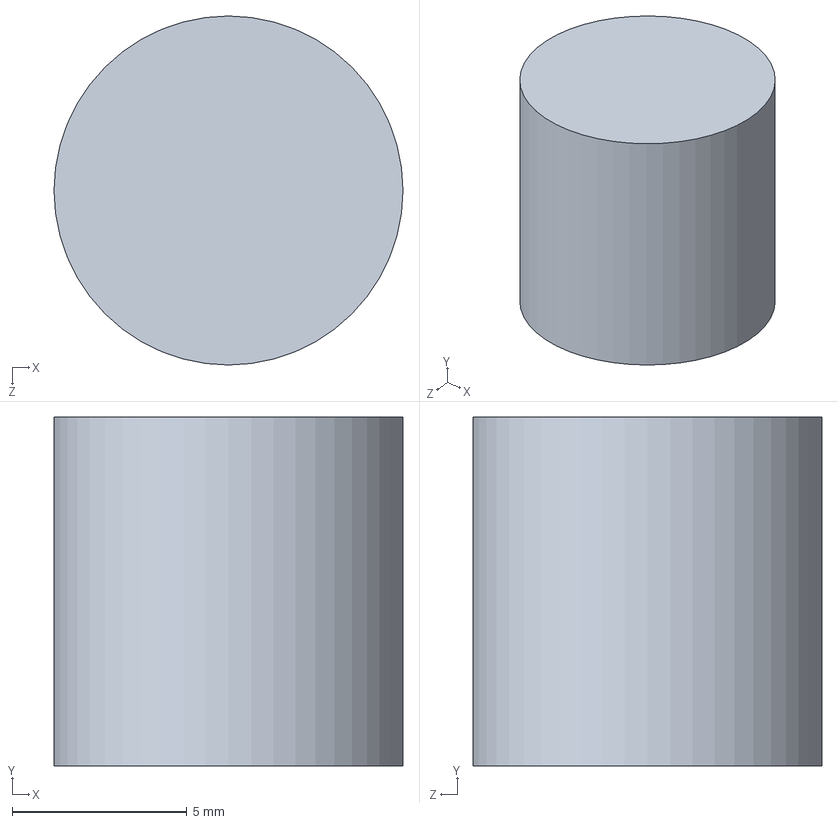
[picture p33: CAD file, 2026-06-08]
chassis/chassis_designes/4.SLDPRT
10.0 x 10.0 x 10.0 mm

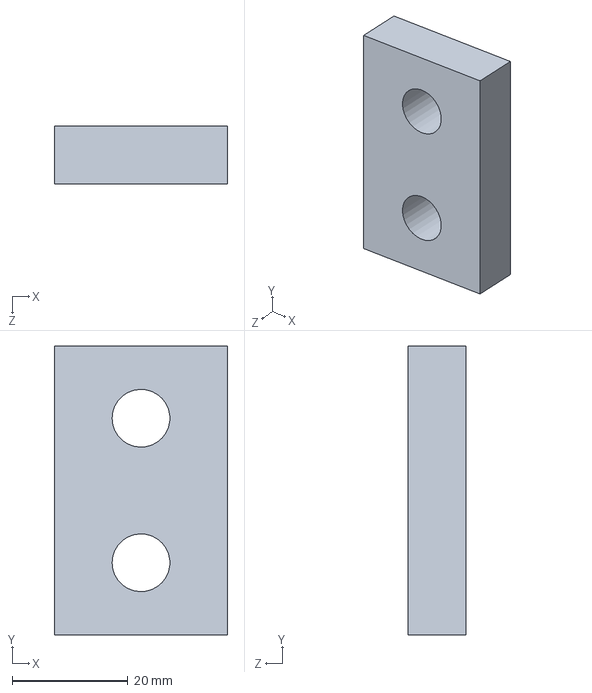
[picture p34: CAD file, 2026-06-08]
chassis/chassis_designes/2.SLDPRT
30.0 x 50.0 x 10.0 mm

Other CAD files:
chassis/chassis_designes/acople izquierdo.SLDPRT
chassis/chassis_designes/acople derecho.STL
chassis/chassis_designes/acople izquierdo.STL
chassis/chassis_planes/Pieza1.SLDDRW
hardware/carcasa/02_consola/MANDO/BASE.3mf
hardware/carcasa/02_consola/MANDO/BOTONCITO.3mf
hardware/carcasa/02_consola/MANDO/TAPA.3MF

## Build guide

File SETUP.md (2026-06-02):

# Guía de instalación y configuración

## Requisitos previos

- Raspberry Pi con RPi OS Lite 64-bit
- 2x ESP32 (WROOM-32 o similar)
- PC/Laptop con Python 3.10+
- ESP-IDF v5.0+ instalado
- Cables Dupont, BTS7960, relé 5V, LCD 16x2 I2C

## Paso 1 — Configurar la Raspberry Pi

Ver guía completa: [docs/05_Instalacion_RPi.md](docs/05_Instalacion_RPi.md)

Resumen:
```bash
# SSH a la RPi
ssh raspi@192.168.1.100

# Instalar Mosquitto
sudo apt install -y mosquitto mosquitto-clients
sudo systemctl enable mosquitto

# Configurar Mosquitto para conexiones externas
echo "listener 1883\nallow_anonymous true" | sudo tee -a /etc/mosquitto/mosquitto.conf
sudo systemctl restart mosquitto
```

## Paso 2 — Configurar Access Point en la RPi

Ver guía completa: [docs/08_AccessPoint_RPi.md](docs/08_AccessPoint_RPi.md)

```bash
sudo nmcli con add type wifi ifname wlan0 con-name CintaAP autoconnect yes ssid CintaTransportadora
sudo nmcli con modify CintaAP 802-11-wireless.mode ap ipv4.method shared ipv4.addresses 192.168.4.1/24
sudo nmcli con modify CintaAP wifi-sec.key-mgmt wpa-psk wifi-sec.psk "cinta2026"
sudo nmcli con up CintaAP
```

Red resultante:
- **SSID:** `CintaTransportadora`
- **Contraseña:** `cinta2026`
- **IP del broker MQTT:** `192.168.4.1:1883`

## Paso 3 — Flashear ESP32 Motor

```bash
cd esp32/motor_controller
idf.py set-target esp32
idf.py build
idf.py -p COM3 flash monitor   # Windows: COM3 | Linux: /dev/ttyUSB0
```

Verificar en monitor serial:
```
I (XXXX) WIFI: IP obtenida: 192.168.4.XX
I (XXXX) MQTT: Conectado al broker
```

## Paso 4 — Flashear ESP32 Consola

```bash
cd esp32/console_esp32
idf.py set-target esp32
idf.py build
idf.py -p COM4 flash monitor   # Windows: COM4 | Linux: /dev/ttyUSB1
```

La LCD debe mostrar:
```
OK:0     Rej:0
Estado: esperando
```

## Paso 5 — Instalar dependencias Python

```bash
pip install -r requirements/rpi_requirements.txt
pip install -r requirements/ml_requirements.txt
```

## Paso 6 — Probar con simulador (sin OpenCV)

```bash
# Conectar PC a la red CintaTransportadora
python scripts/simulador_vision.py
```

## Paso 7 — Módulo de visión artificial

Ver [docs/09_Vision_Artificial.md](docs/09_Vision_Artificial.md) (en desarrollo)

```bash
# Próximamente — Semana 4
python rpi/src/vision/clasificador.py
```

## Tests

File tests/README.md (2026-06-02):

# Tests

## Pruebas de integración

### Test 1 — MQTT end-to-end

```bash
# Terminal 1: suscribir a todos los tópicos
mosquitto_sub -h 192.168.4.1 -t "#" -v

# Terminal 2: simular veredictos
python ../scripts/simulador_vision.py
```

Verificar que:
- ESP32 Motor arranca al recibir `operario/comando = "iniciar"`
- Válvula se activa al recibir `fruta/estado = "rechazada"`
- LCD consola muestra contadores actualizados

### Test 2 — Consola portátil

1. Presionar Botón INICIAR → motor debe arrancar
2. Presionar Botón DETENER → motor debe parar
3. Enviar 3 rechazos consecutivos → LED debe parpadear, pantalla cambia a ALERTA
4. Presionar Botón RESET → alerta se limpia, contadores a cero

### Test 3 — Portabilidad sin internet

1. Desconectar el cable Ethernet de la RPi del router
2. Verificar que la red `CintaTransportadora` sigue activa
3. Confirmar que MQTT sigue funcionando entre todos los dispositivos
4. El sistema debe funcionar completamente sin internet

## Prueba rápida desde la RPi

```bash
ssh raspi@192.168.4.1

# Iniciar sistema
mosquitto_pub -h localhost -t "operario/comando" -m "iniciar"

# Simular frutas
mosquitto_pub -h localhost -t "fruta/estado" -m "aceptada"
mosquitto_pub -h localhost -t "fruta/estado" -m "rechazada"

# Detener
mosquitto_pub -h localhost -t "operario/comando" -m "detener"
```

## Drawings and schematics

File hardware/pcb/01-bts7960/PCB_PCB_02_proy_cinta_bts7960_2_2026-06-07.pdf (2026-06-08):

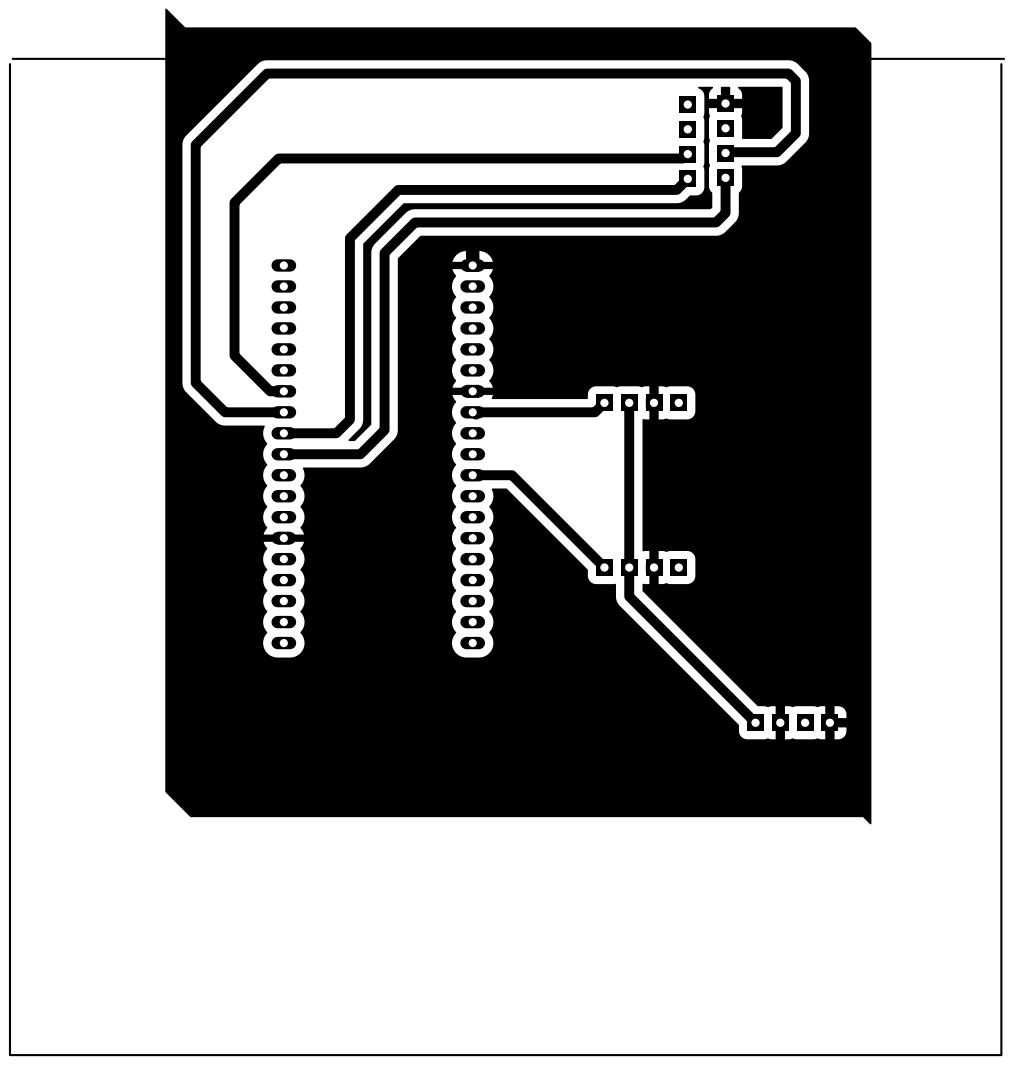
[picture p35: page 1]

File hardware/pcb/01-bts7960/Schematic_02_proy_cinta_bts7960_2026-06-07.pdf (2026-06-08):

A | A

1

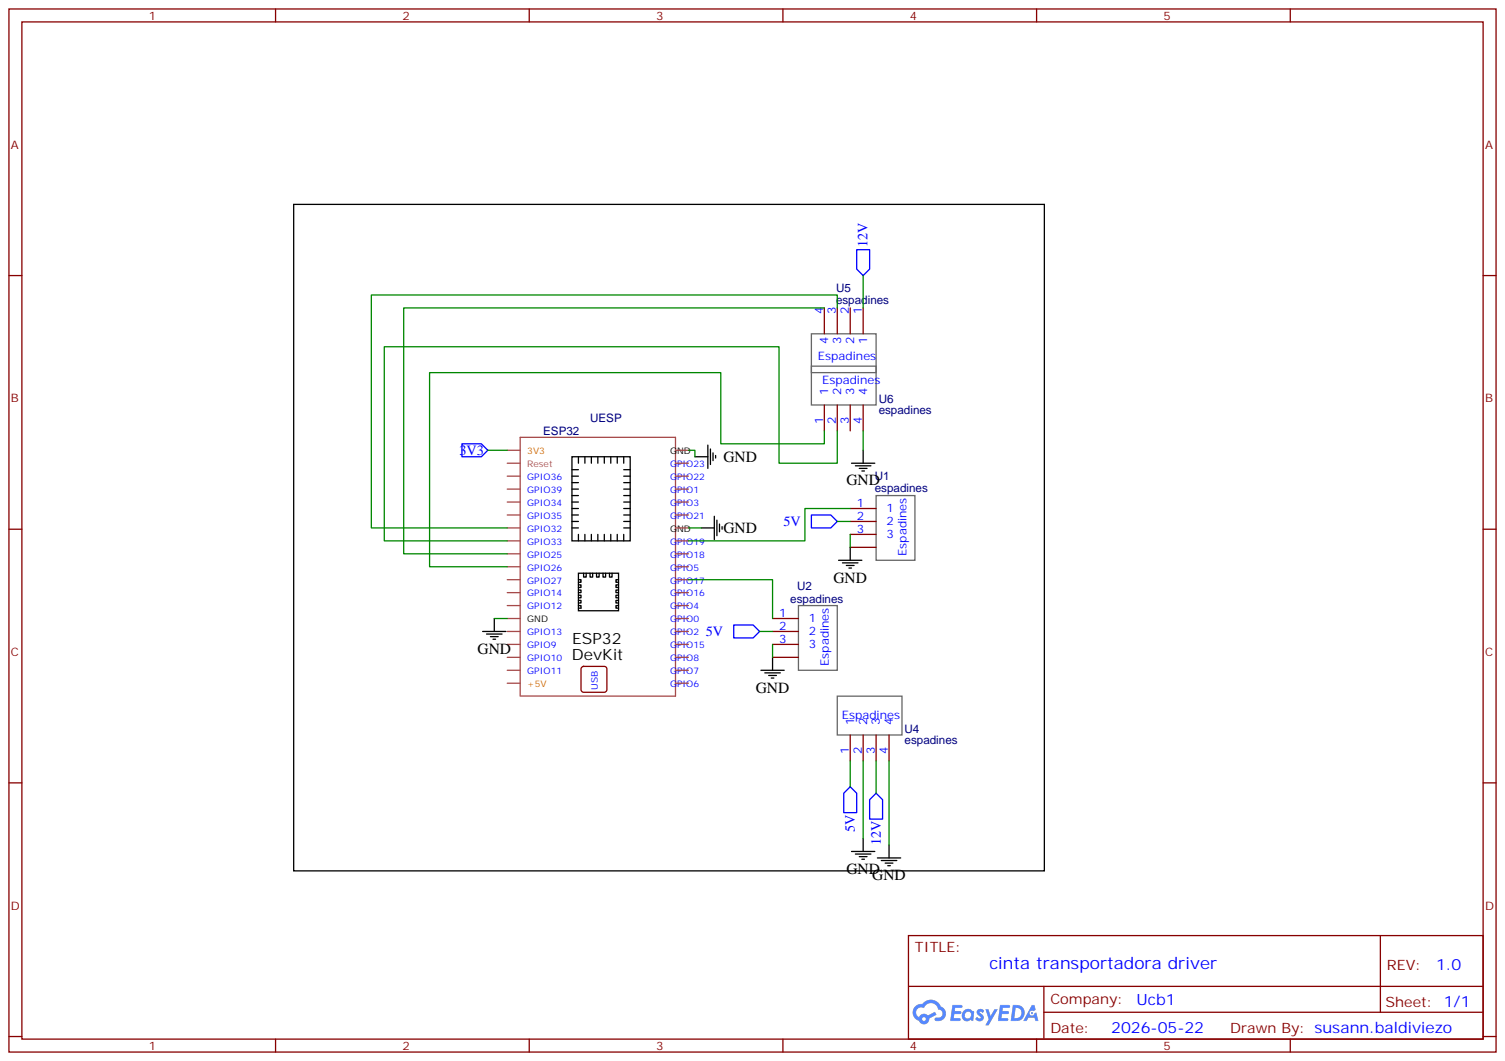
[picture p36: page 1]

Drawn By: susann.baldiviezo

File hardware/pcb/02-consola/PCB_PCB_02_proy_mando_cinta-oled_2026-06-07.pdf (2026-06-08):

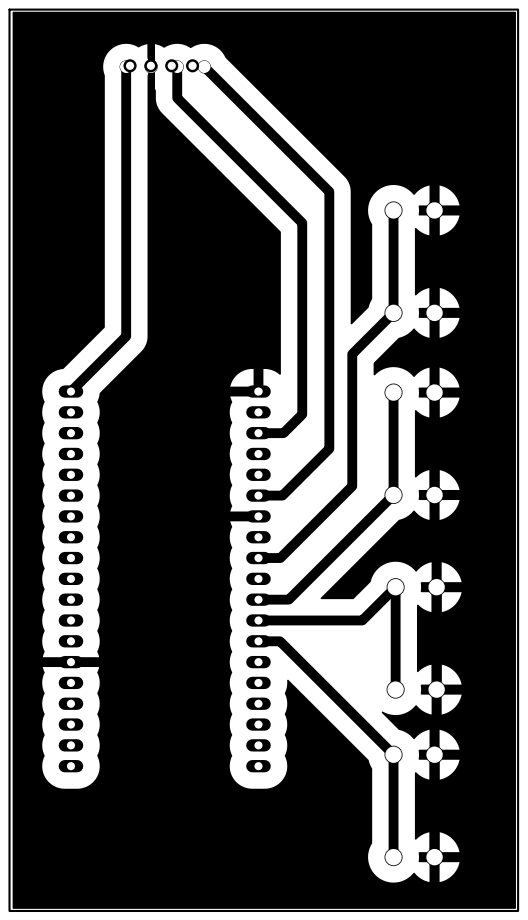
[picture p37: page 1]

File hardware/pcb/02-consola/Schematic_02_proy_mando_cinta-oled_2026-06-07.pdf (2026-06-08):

A | A

1

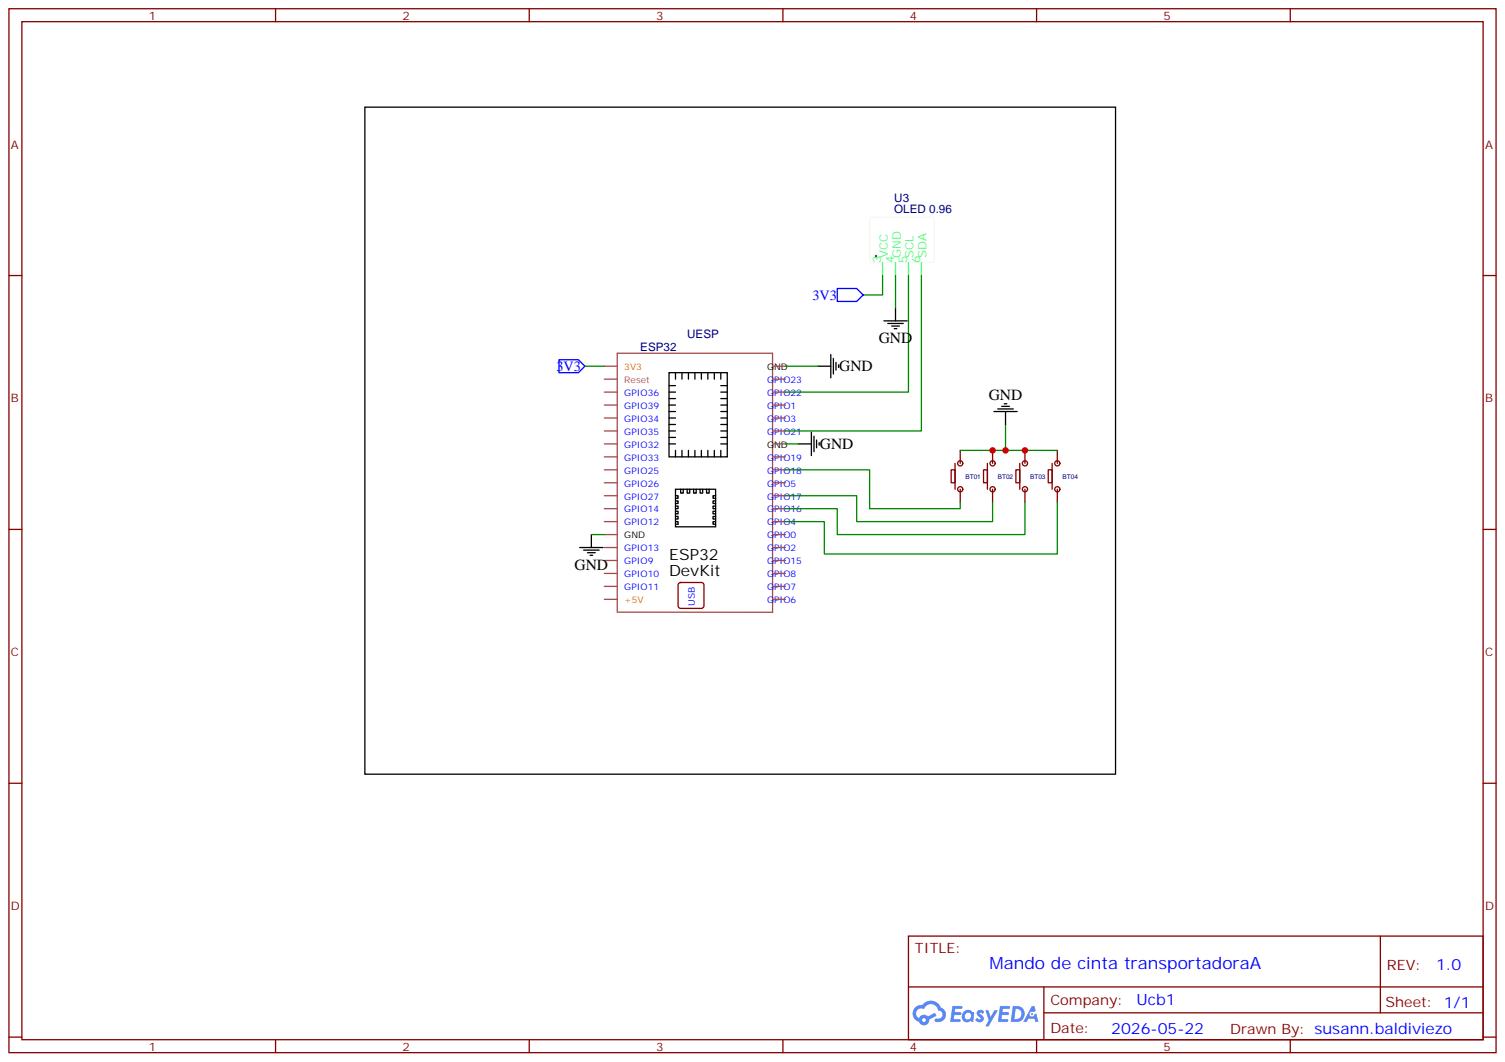
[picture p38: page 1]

Drawn By: susann.baldiviezo

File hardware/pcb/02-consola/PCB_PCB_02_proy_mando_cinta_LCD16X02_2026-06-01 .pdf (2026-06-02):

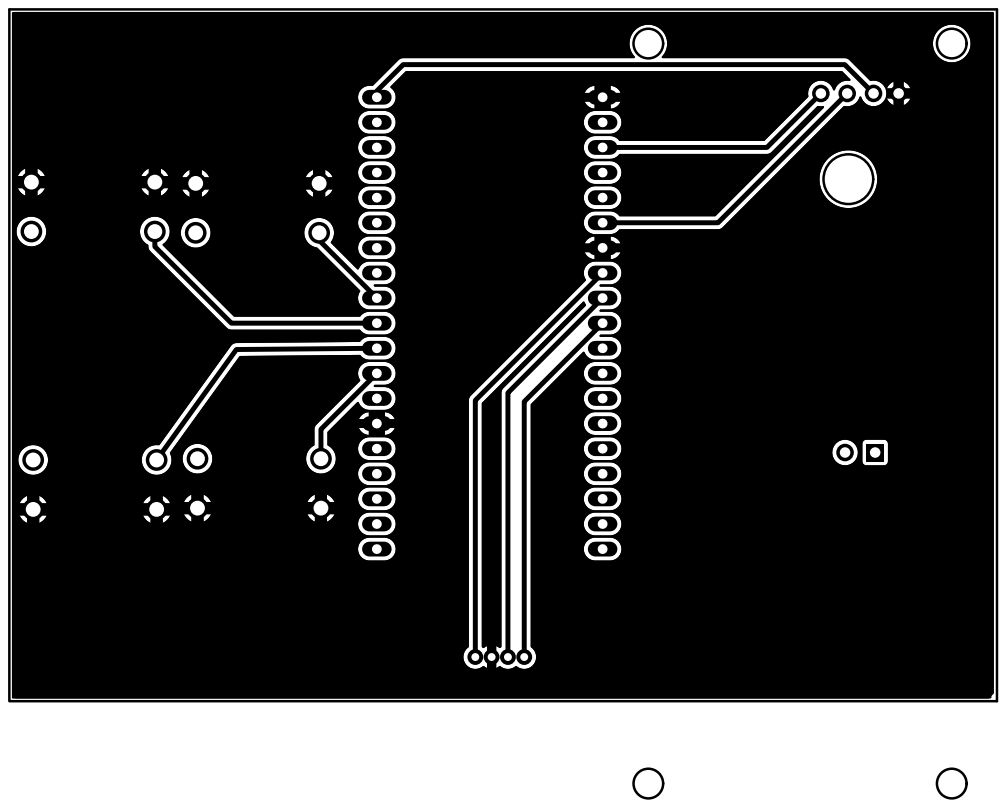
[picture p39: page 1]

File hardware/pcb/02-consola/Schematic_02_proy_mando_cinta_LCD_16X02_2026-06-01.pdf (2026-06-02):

A | A

1

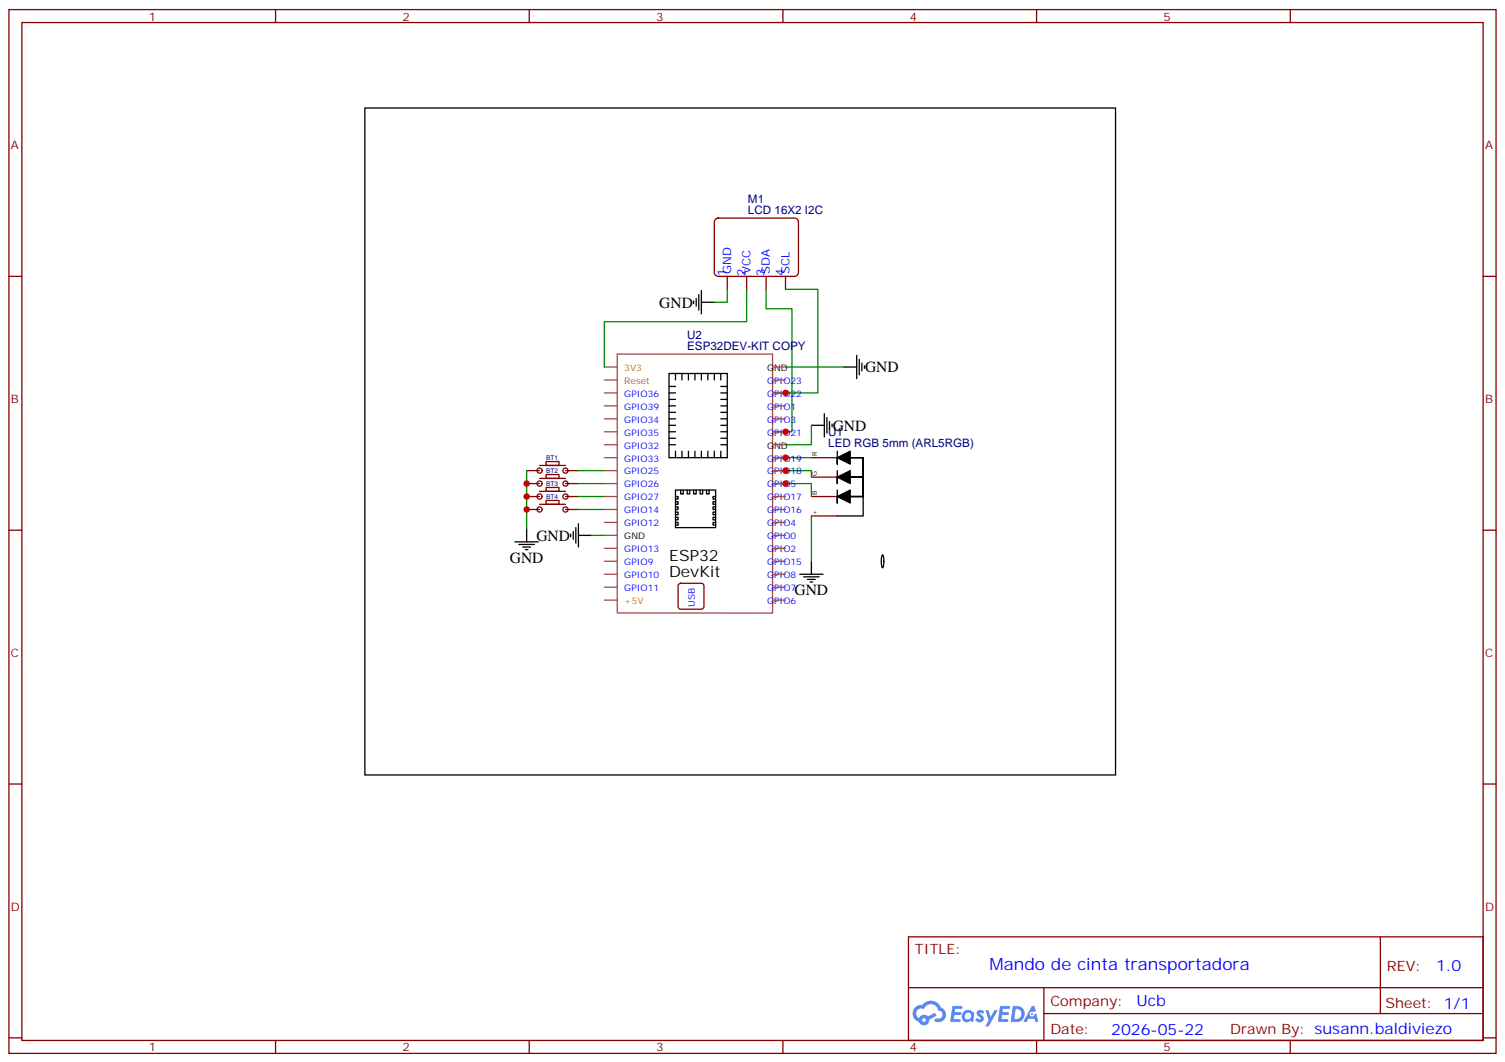
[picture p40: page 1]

Drawn By: susann.baldiviezo

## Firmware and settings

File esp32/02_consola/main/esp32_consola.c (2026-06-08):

/* ================================================================
 * ESP32 CONSOLA — Sistema Clasificador de Frutas
 * Hardware: LCD 16x2 I2C + 4 pulsadores + LED
 * Comunicación: WiFi + MQTT (suscriptor + publicador de comandos)
 * ================================================================ */

#include <stdio.h>
#include <string.h>
#include "freertos/FreeRTOS.h"
#include "freertos/task.h"
#include "esp_wifi.h"
#include "esp_event.h"
#include "esp_log.h"
#include "nvs_flash.h"
#include "driver/gpio.h"
#include "mqtt_client.h"
// #include "lcd_i2c.h"
#include "oled_u8g2.h"
/* ───── RED ───── */
#define WIFI_SSID      "CintaTransportadora"
#define WIFI_PASSWORD  "cinta2026"
#define MQTT_BROKER    "mqtt://192.168.4.1:1883"

/* ───── PINES ───── */
#define PIN_SDA        21
#define PIN_SCL        22
#define BTN_INICIAR    GPIO_NUM_18
#define BTN_DETENER    GPIO_NUM_17
#define BTN_PANTALLA   GPIO_NUM_16
#define BTN_RESET      GPIO_NUM_4
#define PIN_LED        GPIO_NUM_2

/* ───── TÓPICOS MQTT ───── */
#define TOPIC_FRUTA    "fruta/estado"
#define TOPIC_COMANDO  "operario/comando"
#define TOPIC_MOTOR    "sistema/motor"
#define TOPIC_VALVULA  "sistema/valvula"

static const char *TAG = "CONSOLA";
static esp_mqtt_client_handle_t cliente_mqtt = NULL;

/* ───── ESTADO COMPARTIDO ───── */
typedef struct {
    int aceptadas;
    int podridas;
    int verdes;
    int rechazos_consecutivos;
    char estado_motor[16];   // "activo" / "detenido" / "esperando"
    int pantalla_actual;     // 0 = contadores, 1 = diagnóstico, 2 = alerta
    bool alerta_activa;
    bool wifi_ok;
    volatile bool lcd_needs_update;
} estado_t;

static estado_t S = {
    .aceptadas = 0,
    .podridas = 0,
    .verdes = 0,
    .rechazos_consecutivos = 0,
    .estado_motor = "esperando",
    .pantalla_actual = 0,
    .alerta_activa = false,
    .wifi_ok = false,
    .lcd_needs_update = true,
};

/* ════════════════════════════════════════════════════════════════
 * RENDERIZAR PANTALLA SEGÚN VISTA ACTUAL
 * ════════════════════════════════════════════════════════════════ */
static void render_pantalla(void)
{
    oled_render_pantalla(S.pantalla_actual, S.aceptadas, S.podridas, S.verdes, S.estado_motor, S.wifi_ok, S.rechazos_consecutivos);
}

/* ════════════════════════════════════════════════════════════════
 * TAREA: BOTONES
 * ════════════════════════════════════════════════════════════════ */
static void tarea_botones(void *param)
{
    gpio_config_t cfg = {
        .pin_bit_mask = (1ULL << BTN_INICIAR) | (1ULL << BTN_DETENER) |
                        (1ULL << BTN_PANTALLA) | (1ULL << BTN_RESET),
        .mode         = GPIO_MODE_INPUT,
        .pull_up_en   = GPIO_PULLUP_ENABLE,
        .pull_down_en = GPIO_PULLDOWN_DISABLE,
        .intr_type    = GPIO_INTR_DISABLE,
    };
    gpio_config(&cfg);

    int last1 = 1, last2 = 1, last3 = 1, last4 = 1;

    while (1) {
        int b1 = gpio_get_level(BTN_INICIAR);
        int b2 = gpio_get_level(BTN_DETENER);
        int b3 = gpio_get_level(BTN_PANTALLA);
        int b4 = gpio_get_level(BTN_RESET);

        if (last1 == 1 && b1 == 0) {
            // Solo permite iniciar si no esta "iniciando" ni "activo"
            if (strcmp(S.estado_motor, "iniciando") != 0 && strcmp(S.estado_motor, "activo") != 0) {
                ESP_LOGI(TAG, "Botón INICIAR presionado");
                if (cliente_mqtt) {
                    esp_mqtt_client_publish(cliente_mqtt, TOPIC_COMANDO, "iniciar", 0, 1, 0);
                    strncpy(S.estado_motor, "iniciando", sizeof(S.estado_motor) - 1);
                    S.lcd_needs_update = true;
                } else {
                    ESP_LOGW(TAG, "INICIAR ignorado: MQTT no conectado aún");
                }
            } else {
                ESP_LOGI(TAG, "Ignorado: Ya está iniciado (%s)", S.estado_motor);
            }
        }
        if (last2 == 1 && b2 == 0) {
            // Solo permite detener si esta "iniciando" o "activo"
            if (strcmp(S.estado_motor, "iniciando") == 0 || strcmp(S.estado_motor, "activo") == 0) {
                ESP_LOGI(TAG, "Botón DETENER presionado");
                if (cliente_mqtt) {
                    esp_mqtt_client_publish(cliente_mqtt, TOPIC_COMANDO, "detener", 0, 1, 0);
                    strncpy(S.estado_motor, "deteniendo", sizeof(S.estado_motor) - 1);
                    S.lcd_needs_update = true;
                } else {
                    ESP_LOGW(TAG, "DETENER ignorado: MQTT no conectado aún");
                }
            } else {
                ESP_LOGI(TAG, "Ignorado: Ya está detenido (%s)", S.estado_motor);
            }
        }
        if (last3 == 1 && b3 == 0) {
            S.pantalla_actual = (S.pantalla_actual + 1) % 3;
            ESP_LOGI(TAG, "Pantalla cambiada a %d", S.pantalla_actual);
            // Publicar pantalla al dashboard
            if (cliente_mqtt) {
                char buf[4];
                snprintf(buf, sizeof(buf), "%d", S.pantalla_actual);
                esp_mqtt_client_publish(cliente_mqtt, "consola/pantalla", buf, 0, 0, 0);
            }
            S.lcd_needs_update = true;
        }
        if (last4 == 1 && b4 == 0) {
            ESP_LOGI(TAG, "Contadores reseteados");
            S.aceptadas = 0;
            S.podridas = 0;
            S.verdes = 0;
            S.rechazos_consecutivos = 0;
            S.alerta_activa = false;
            // Notificar reset al dashboard
            if (cliente_mqtt) {
                esp_mqtt_client_publish(cliente_mqtt, "consola/reset", "reset", 0, 0, 0);
            }
            S.lcd_needs_update = true;
        }

        last1 = b1; last2 = b2; last3 = b3; last4 = b4;
        vTaskDelay(pdMS_TO_TICKS(30));  // Antirrebote 30ms (más estable)
    }
}

/* ════════════════════════════════════════════════════════════════
 * TAREA: LED DE ESTADO
 * ════════════════════════════════════════════════════════════════ */
static void tarea_led(void *param)
{
    gpio_config_t cfg = {
        .pin_bit_mask = 1ULL << PIN_LED,
        .mode         = GPIO_MODE_OUTPUT,
    };
    gpio_config(&cfg);

    while (1) {
        if (!S.wifi_ok) {
            // Parpadeo rápido = sin WiFi
            gpio_set_level(PIN_LED, 1); vTaskDelay(pdMS_TO_TICKS(150));
            gpio_set_level(PIN_LED, 0); vTaskDelay(pdMS_TO_TICKS(150));
        } else if (S.alerta_activa) {
            // Parpadeo lento = alerta
            gpio_set_level(PIN_LED, 1); vTaskDelay(pdMS_TO_TICKS(500));
            gpio_set_level(PIN_LED, 0); vTaskDelay(pdMS_TO_TICKS(500));
        } else {
            gpio_set_level(PIN_LED, S.wifi_ok ? 1 : 0);
            vTaskDelay(pdMS_TO_TICKS(500));
        }
    }
}

/* ════════════════════════════════════════════════════════════════
 * TAREA: ACTUALIZAR LCD (separada para no bloquear botones)
 * ════════════════════════════════════════════════════════════════ */
static void tarea_lcd(void *param)
{
    while (1) {
        if (S.lcd_needs_update) {
            S.lcd_needs_update = false;
            render_pantalla();
        }
        vTaskDelay(pdMS_TO_TICKS(10)); // Refresco instantáneo
    }
}

/* ════════════════════════════════════════════════════════════════
 * HANDLER MQTT
 * ════════════════════════════════════════════════════════════════ */
static void mqtt_event_handler(void *handler_args, esp_event_base_t base,
                               int32_t event_id, void *event_data)
{
    esp_mqtt_event_handle_t event  = event_data;
    esp_mqtt_client_handle_t client = event->client;
    char topic[64];
    char data[64];

    switch ((esp_mqtt_event_id_t)event_id) {

    case MQTT_EVENT_CONNECTED:
        ESP_LOGI(TAG, "MQTT conectado");
        esp_mqtt_client_subscribe(client, TOPIC_FRUTA, 1);
        esp_mqtt_client_subscribe(client, TOPIC_MOTOR, 1);
        esp_mqtt_client_subscribe(client, TOPIC_VALVULA, 1);
        esp_mqtt_client_subscribe(client, TOPIC_COMANDO, 1);
        S.wifi_ok = true;
        S.lcd_needs_update = true;
        break;

    case MQTT_EVENT_DISCONNECTED:
        ESP_LOGW(TAG, "MQTT desconectado");
        S.wifi_ok = false;
        S.lcd_needs_update = true;
        break;

    case MQTT_EVENT_DATA:
        snprintf(topic, sizeof(topic), "%.*s", event->topic_len, event->topic);
        snprintf(data,  sizeof(data),  "%.*s", event->data_len,  event->data);
        ESP_LOGI(TAG, "[%s] = %s", topic, data);

        /* ── ESTADO DEL MOTOR (enviado por la cinta) ── */
        if (strcmp(topic, TOPIC_MOTOR) == 0) {
            strncpy(S.estado_motor, data, sizeof(S.estado_motor) - 1);
            S.estado_motor[sizeof(S.estado_motor) - 1] = '\0';
            S.lcd_needs_update = true;
        }

        /* ── COMANDO OPERARIO (desde RPi/PC/botones remotos) ── */
        else if (strcmp(topic, TOPIC_COMANDO) == 0) {
            if (strcmp(data, "iniciar") == 0) {
                strncpy(S.estado_motor, "iniciando", sizeof(S.estado_motor) - 1);
            } else if (strcmp(data, "detener") == 0) {
                strncpy(S.estado_motor, "deteniendo", sizeof(S.estado_motor) - 1);
            }
            S.estado_motor[sizeof(S.estado_motor) - 1] = '\0';
            S.lcd_needs_update = true;
        }

        /* ── VEREDICTO DE FRUTA ── */
        else if (strcmp(topic, TOPIC_FRUTA) == 0) {
            if (strcmp(data, "aceptada") == 0) {
                S.aceptadas++;
                S.rechazos_consecutivos = 0;
                S.alerta_activa = false;
            } else if (strcmp(data, "podrida") == 0) {
                S.podridas++;
                S.rechazos_consecutivos++;
                if (S.rechazos_consecutivos >= 3) {
                    S.alerta_activa = true;
                    S.pantalla_actual = 2;
                }
            } else if (strcmp(data, "verde") == 0) {
                S.verdes++;
                S.rechazos_consecutivos++;
                if (S.rechazos_consecutivos >= 3) {
                    S.alerta_activa = true;
                    S.pantalla_actual = 2;
                }
            }
            S.lcd_needs_update = true;
        }
        break;

    case MQTT_EVENT_ERROR:
        ESP_LOGE(TAG, "Error en cliente MQTT");
        break;

    default:
        break;
    }
}

/* ════════════════════════════════════════════════════════════════
 * HANDLER WIFI
 * ════════════════════════════════════════════════════════════════ */
static void wifi_event_handler(void *arg, esp_event_base_t base,
                               int32_t event_id, void *event_data)
{
    if (base == WIFI_EVENT && event_id == WIFI_EVENT_STA_START) {
        esp_wifi_connect();
    }
    else if (base == WIFI_EVENT && event_id == WIFI_EVENT_STA_DISCONNECTED) {
        S.wifi_ok = false;
        S.lcd_needs_update = true;
        esp_wifi_connect();
    }
    else if (base == IP_EVENT && event_id == IP_EVENT_STA_GOT_IP) {
        ip_event_got_ip_t *event = (ip_event_got_ip_t *) event_data;
        ESP_LOGI(TAG, "WiFi conectado. IP: " IPSTR, IP2STR(&event->ip_info.ip));

        // Iniciar cliente MQTT
        esp_mqtt_client_config_t mqtt_cfg = {
            .broker.address.uri = MQTT_BROKER,
        };
        esp_mqtt_client_handle_t client = esp_mqtt_client_init(&mqtt_cfg);
        esp_mqtt_client_register_event(client, ESP_EVENT_ANY_ID, mqtt_event_handler, NULL);
        esp_mqtt_client_start(client);
        cliente_mqtt = client;
    }
}

/* ════════════════════════════════════════════════════════════════
 * INICIALIZACIÓN WIFI
 * ════════════════════════════════════════════════════════════════ */
static void wifi_init(void)
{
    ESP_ERROR_CHECK(esp_netif_init());
    ESP_ERROR_CHECK(esp_event_loop_create_default());
    esp_netif_create_default_wifi_sta();

    wifi_init_config_t cfg = WIFI_INIT_CONFIG_DEFAULT();
    ESP_ERROR_CHECK(esp_wifi_init(&cfg));

    ESP_ERROR_CHECK(esp_event_handler_register(WIFI_EVENT, ESP_EVENT_ANY_ID, wifi_event_handler, NULL));
    ESP_ERROR_CHECK(esp_event_handler_register(IP_EVENT,   IP_EVENT_STA_GOT_IP, wifi_event_handler, NULL));

    wifi_config_t wifi_config = {
        .sta = {
            .ssid     = WIFI_SSID,
            .password = WIFI_PASSWORD,
        },
    };
    esp_wifi_set_mode(WIFI_MODE_STA);
    esp_wifi_set_config(WIFI_IF_STA, &wifi_config);
    ESP_ERROR_CHECK(esp_wifi_start());

    // Reducir potencia TX para evitar caídas de voltaje en la PCB
    esp_wifi_set_max_tx_power(40); // 10 dBm (~150mA pico vs 450mA default)
}

/* ════════════════════════════════════════════════════════════════
 * APP MAIN
 * ════════════════════════════════════════════════════════════════ */
void app_main(void)
{
    ESP_LOGI(TAG, "════════════════════════════════════════");
    ESP_LOGI(TAG, "  ESP32 CONSOLA — Clasificador de Frutas");
    ESP_LOGI(TAG, "════════════════════════════════════════");

    /* NVS */
    esp_err_t ret = nvs_flash_init();
    if (ret == ESP_ERR_NVS_NO_FREE_PAGES || ret == ESP_ERR_NVS_NEW_VERSION_FOUND) {
        nvs_flash_erase();
        nvs_flash_init();
    }

    /* LCD / OLED */
    // lcd_init(PIN_SDA, PIN_SCL);
    // lcd_clear();
    // lcd_set_cursor(0, 0); lcd_print("Iniciando...");
    // lcd_set_cursor(0, 1); lcd_print("Conectando WiFi");
    oled_init(PIN_SDA, PIN_SCL);

    /* Lanzar tareas */
    xTaskCreate(tarea_botones, "botones", 4096, NULL, 5, NULL);
    xTaskCreate(tarea_led,     "led",     2048, NULL, 4, NULL);
    xTaskCreate(tarea_lcd,     "lcd",     4096, NULL, 4, NULL);

    /* WiFi + MQTT */
    wifi_init();

    ESP_LOGI(TAG, "Sistema listo. Esperando eventos...");
}

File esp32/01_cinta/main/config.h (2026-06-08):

#pragma once

/* ================================================================
 * config.h — Configuración central del sistema
 * ================================================================ */

/* ───── RED ───── */
#define WIFI_SSID      "CintaTransportadora"
#define WIFI_PASSWORD  "cinta2026"
#define MQTT_BROKER    "mqtt://192.168.4.1:1883"

/* ───── PINES BTS7960 ───── */
#define PIN_RPWM       GPIO_NUM_25   // PWM giro adelante
#define PIN_LPWM       GPIO_NUM_26   // PWM giro atrás
#define PIN_R_EN       GPIO_NUM_32   // Habilita lado derecho
#define PIN_L_EN       GPIO_NUM_33   // Habilita lado izquierdo

/* ───── SERVOS → CLASIFICACIÓN (MECANISMO DESVÍO) ───── */
#define PIN_SERVO_A      GPIO_NUM_19  // Servo A (izquierda = podrida)
#define PIN_SERVO_B      GPIO_NUM_17  // Servo B (derecha   = verde)

/* ───── ÁNGULOS DE SERVO (° grados) ───── */
/*   maduro   → 45°  (derecha)                              */
/*   pintón/verde → 90° (centro, reposo)                    */
/*   podrido  → 135° (izquierda)                            */
#define SERVO_ANG_CENTRO      90   // pintón / verde / reposo
#define SERVO_ANG_DERECHA     45   // maduro  (derecha)
#define SERVO_ANG_IZQUIERDA  135   // podrido (izquierda)
#define SERVO_B_ESPEJO     false   // true si los servos estan montados enfrentados

/* ───── CANALES LEDC PARA SERVOS ───── */
#define SERVO_TIMER        LEDC_TIMER_1
#define SERVO_CANAL_A      LEDC_CHANNEL_2
#define SERVO_CANAL_B      LEDC_CHANNEL_3
#define SERVO_FREQ_HZ      50           // 50 Hz estándar para servos
#define SERVO_RESOL        LEDC_TIMER_13_BIT  // 8192 counts -> resolucion fina
#define SERVO_PULSE_MIN_US 500           // us a 0 grados
#define SERVO_PULSE_MAX_US 2400          // us a 180 grados

/* ───── CONFIGURACIÓN PWM ───── */
#define PWM_CANAL_R    LEDC_CHANNEL_0
#define PWM_CANAL_L    LEDC_CHANNEL_1
#define PWM_TIMER      LEDC_TIMER_0
#define PWM_FREQ       10000             // 10 kHz — suave para BTS7960
#define PWM_RESOL      LEDC_TIMER_8_BIT // 0–255

/* ───── VELOCIDAD DEL MOTOR ───── */
#define MOTOR_VEL_NORMAL  150   // duty cycle de arranque (0–255)

/* ───── TÓPICOS MQTT ───── */
#define TOPIC_FRUTA    "fruta/estado"
#define TOPIC_COMANDO  "operario/comando"
#define TOPIC_MOTOR    "sistema/motor"
#define TOPIC_VALVULA  "sistema/valvula"

/* ───── TIEMPOS ───── */
/* Tiempo que tarda la fruta en pasar por el mecanismo      */
/* después de que el servo se movió.                        */
/* Ajustar según velocidad real de la cinta.                */
#define FRUTA_TRANSITO_MS   6000   // 6 s hasta que la fruta sale del mecanismo
#define VALVULA_MS           500   // tiempo en ms que el servo mantiene la posicion

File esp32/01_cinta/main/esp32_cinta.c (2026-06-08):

/* ================================================================
 * esp32_cinta.c — Punto de entrada principal
 *
 * Solo contiene app_main(). Toda la lógica está modularizada:
 *   config.h        → pines, red, tópicos MQTT
 *   motor.h/.c      → control BTS7960 (PWM)
 *   valvula.h/.c    → relé + tarea FreeRTOS no bloqueante
 *   mqtt_handler.h/.c → eventos MQTT
 *   wifi_manager.h/.c → conexión WiFi
 * ================================================================ */

#include "esp_log.h"
#include "nvs_flash.h"
#include "motor.h"
#include "servo.h"
#include "wifi_manager.h"
#define WIFI_SSID      "CintaTransportadora"
#define WIFI_PASSWORD  "cinta2026"
#define MQTT_BROKER    "mqtt://192.168.4.1:1883"

static const char *TAG = "CINTA";

void app_main(void)
{
    ESP_LOGI(TAG, "════════════════════════════════════════");
    ESP_LOGI(TAG, "  ESP32 CINTA — Clasificador de Frutas  ");
    ESP_LOGI(TAG, "  Driver: BTS7960                       ");
    ESP_LOGI(TAG, "════════════════════════════════════════");

    /* Inicializar NVS (requerido por WiFi) */
    esp_err_t ret = nvs_flash_init();
    if (ret == ESP_ERR_NVS_NO_FREE_PAGES || ret == ESP_ERR_NVS_NEW_VERSION_FOUND) {
        nvs_flash_erase();
        nvs_flash_init();
    }

    /* Hardware */
    motor_init();
    servo_init();   // también crea la tarea FreeRTOS de los servos/relés
    motor_detener();  // asegurar estado inicial seguro

    /* Red + MQTT (el cliente MQTT arranca automáticamente al obtener IP) */
    wifi_init();

    ESP_LOGI(TAG, "Sistema listo. Esperando comandos MQTT...");
}

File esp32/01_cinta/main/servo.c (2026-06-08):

/* ================================================================
 * servo.c — Control de 2 servomotores sincronizados (GPIO 19 y 17)
 *
 * ESTADOS DEL MECANISMO DE DESVÍO:
 *   maduro   → 45°  (derecha)   — fruta madura
 *   pintón/verde → 90° (centro) — fruta pintona o verde (reposo)
 *   podrido  → 135° (izquierda) — fruta podrida
 *
 * LÓGICA DE TIMING:
 *   1. Llega señal MQTT con el tipo de fruta.
 *   2. Si la posición objetivo es DISTINTA a la actual → mover inmediatamente.
 *      Si ya está en la posición correcta → no hacer nada (evita volver de ida y vuelta).
 *   3. Esperar FRUTA_TRANSITO_MS (6 s) para que la fruta pase el mecanismo.
 *   4. Volver al centro (SERVO_ANG_CENTRO = 90°) listo para la siguiente fruta.
 *
 * Los servos se manejan en una tarea FreeRTOS propia para que el
 * movimiento NUNCA bloquee el hilo del broker MQTT.
 * ================================================================ */

#include <math.h>
#include <limits.h>
#include "freertos/FreeRTOS.h"
#include "freertos/task.h"
#include "driver/ledc.h"
#include "driver/gpio.h"
#include "esp_log.h"
#include "mqtt_client.h"
#include "config.h"
#include "servo.h"

static const char *TAG = "SERVO";

/* Handle de la tarea — necesario para enviarle notificaciones */
static TaskHandle_t tarea_servo_handle = NULL;

/* Posicion actual (en grados) de ambos servos (pos_a = referencia) */
static int pos_a = SERVO_ANG_CENTRO;
static int pos_b = SERVO_ANG_CENTRO;

/* Ultima accion ejecutada — para evitar mover si ya estamos en posicion */
static uint32_t ultimo_estado = 0;   /* 0 = ninguno aun */

/* Cliente MQTT compartido (se asigna desde mqtt_handler) */
extern esp_mqtt_client_handle_t cliente_mqtt;

/* ── Codigos de accion ── */
#define ACCION_MADURO   1   /* 45°  derecha */
#define ACCION_PINTON   2   /* 90°  centro  */
#define ACCION_PODRIDO  3   /* 135° izquierda */

/* ────────────────────────────────────────────────────────────────
 * Convierte grados (0–180) a duty cycle para LEDC_TIMER_13_BIT
 * Periodo servo = 20 000 µs (50 Hz)
 * 8192 counts = 20 000 µs
 * duty = counts * (pulse_us / 20000)
 * ──────────────────────────────────────────────────────────────── */
static uint32_t angulo_a_duty(int grados)
{
    if (grados < 0)   grados = 0;
    if (grados > 180) grados = 180;

    uint32_t pulse_us = SERVO_PULSE_MIN_US +
                        (uint32_t)(grados) * (SERVO_PULSE_MAX_US - SERVO_PULSE_MIN_US) / 180;

    return (pulse_us * 8192U) / 20000U;
}

/* Angulo del servo B segun modo espejo */
static int angulo_b(int ang)
{
    return SERVO_B_ESPEJO ? (180 - ang) : ang;
}

/* ────────────────────────────────────────────────────────────────
 * Escribe el angulo directamente (sin suavizado) en ambos servos
 * ──────────────────────────────────────────────────────────────── */
static void servo_set_raw(int a, int b)
{
    ledc_set_duty(LEDC_LOW_SPEED_MODE, SERVO_CANAL_A, angulo_a_duty(a));
    ledc_update_duty(LEDC_LOW_SPEED_MODE, SERVO_CANAL_A);
    ledc_set_duty(LEDC_LOW_SPEED_MODE, SERVO_CANAL_B, angulo_a_duty(b));
    ledc_update_duty(LEDC_LOW_SPEED_MODE, SERVO_CANAL_B);
    pos_a = a;
    pos_b = b;
}

/* ────────────────────────────────────────────────────────────────
 * Mueve AMBOS servos de forma sincronizada y suave
 * ──────────────────────────────────────────────────────────────── */
static void mover_sync(int objetivo_a, int objetivo_b)
{
    int inicio_a = pos_a;
    int inicio_b = pos_b;

    int pasos = abs(objetivo_a - inicio_a);
    if (abs(objetivo_b - inicio_b) > pasos)
        pasos = abs(objetivo_b - inicio_b);

    if (pasos == 0) {
        servo_set_raw(objetivo_a, objetivo_b);
        return;
    }

    for (int i = 1; i <= pasos; i++) {
        int a = inicio_a + (objetivo_a - inicio_a) * i / pasos;
        int b = inicio_b + (objetivo_b - inicio_b) * i / pasos;
        servo_set_raw(a, b);
        vTaskDelay(pdMS_TO_TICKS(12)); /* ~12ms por paso: suave y preciso */
    }
}

/* ────────────────────────────────────────────────────────────────
 * Tarea privada: espera notificacion, actua y espera transito
 *
 * FLUJO por señal recibida:
 *   1. Recibir accion por xTaskNotifyWait
 *   2. Si el objetivo es IGUAL al estado actual → no mover nada
 *   3. Si es diferente → mover servos AL INSTANTE al angulo objetivo
 *   4. Esperar FRUTA_TRANSITO_MS para que la fruta cruce el mecanismo
 *   5. Volver al centro (pintón/reposo)
 *   6. Actualizar ultimo_estado → listo para la siguiente señal
 * ──────────────────────────────────────────────────────────────── */
static void tarea_servo(void *arg)
{
    uint32_t accion = 0;

    /* Posicion inicial: centro */
    servo_set_raw(SERVO_ANG_CENTRO, angulo_b(SERVO_ANG_CENTRO));
    ultimo_estado = ACCION_PINTON;

    while (1) {
        xTaskNotifyWait(0x00, ULONG_MAX, &accion, portMAX_DELAY);

        /* ── Determinar angulo objetivo ── */
        int objetivo = SERVO_ANG_CENTRO;
        const char *mqtt_payload = "centro";
        const char *nombre = "pintón/verde";

        if (accion == ACCION_MADURO) {
            objetivo      = SERVO_ANG_DERECHA;
            mqtt_payload  = "desvio_der";
            nombre        = "MADURO (derecha 45°)";
        } else if (accion == ACCION_PINTON) {
            objetivo      = SERVO_ANG_CENTRO;
            mqtt_payload  = "centro";
            nombre        = "PINTÓN/VERDE (centro 90°)";
        } else if (accion == ACCION_PODRIDO) {
            objetivo      = SERVO_ANG_IZQUIERDA;
            mqtt_payload  = "desvio_izq";
            nombre        = "PODRIDO (izquierda 135°)";
        } else {
            /* accion desconocida, ignorar */
            continue;
        }

        /* ── Si ya estamos en la posicion correcta, no hacer nada ── */
        if (accion == ultimo_estado && pos_a == objetivo) {
            ESP_LOGI(TAG, ">>> Ya en posicion %s — sin movimiento innecesario", nombre);
            continue;   /* esperar la siguiente señal directamente */
        }

        /* ── Mover inmediatamente al angulo objetivo ── */
        ESP_LOGI(TAG, ">>> Moviendo a %s", nombre);
        mover_sync(objetivo, angulo_b(objetivo));
        ultimo_estado = accion;

        /* Publicar confirmacion de movimiento */
        if (cliente_mqtt) {
            esp_mqtt_client_publish(cliente_mqtt, TOPIC_VALVULA, mqtt_payload, 0, 1, 0);
        }

        /* ── Esperar a que la fruta cruce el mecanismo ── */
        ESP_LOGI(TAG, ">>> Esperando %d ms para que pase la fruta...", FRUTA_TRANSITO_MS);
        vTaskDelay(pdMS_TO_TICKS(FRUTA_TRANSITO_MS));

        /* ── Volver al centro listo para la siguiente fruta ── */
        ESP_LOGI(TAG, ">>> Volviendo al centro (reposo)");
        mover_sync(SERVO_ANG_CENTRO, angulo_b(SERVO_ANG_CENTRO));
        ultimo_estado = ACCION_PINTON;   /* ahora estamos en el centro */
    }
}
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

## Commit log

2026-06-02 feat: initial project structure for fruit classification system
    - Add professional folder structure for mechatronic project
    - Add documentation (README, ARCHITECTURE, SETUP)
    - Add ESP32 firmware for motor controller and console
    - Add Raspberry Pi configuration and MQTT setup
    - Add hardware and ML folder structure
    - Add scripts and requirements
    - Configure Mosquitto MQTT broker
    [config.h, esp32_cinta.c, esp32_consola.c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]
2026-06-02 docs: update RPi README with configuration details
    - Add detailed SSH access instructions
    - Add configuration files table
    - Add frequent use commands
    - Add network switching commands (AP vs client mode)
2026-06-08 Pinout ESP32
2026-06-08 Docs: Actualizar README con enfoque regional de Tarija y componentes finales
2026-06-08 planificacion: nuevos archivos hardware, consola esp32 y docs
    [BASE.3mf, BASE.SLDPRT, BOTONCITO.3mf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]
